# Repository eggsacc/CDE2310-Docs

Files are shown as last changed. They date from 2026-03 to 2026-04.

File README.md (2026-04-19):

# CDE2310 AY2526 S2 Group 5 


[]()

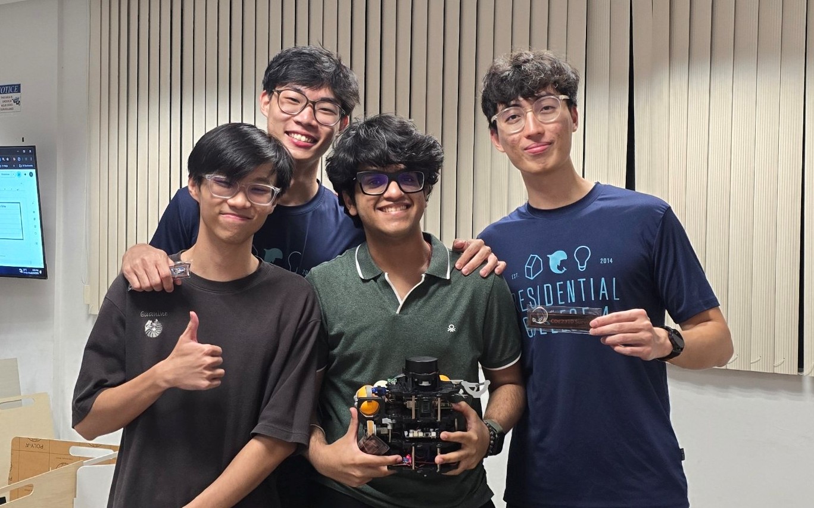
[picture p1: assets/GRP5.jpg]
grp5


[Watch the Mission Recording here](https://www.youtube.com/watch?v=zkyW6KsJtYI)

## Mission Overview
The main objective of this project is to design, create and validate an autonomous mobile robot (AMR system) based on the Turtlebot3 system to simulate intralogistics operations in a simulated smart warehouse environment. The AMR system must be capable of autonomously navigating an unknown maze-like environment while constructing a map of the environment, localizing itself and carrying out a series of tasks to deliver three ping pong balls into pre identified receptacles (static and dynamic) without human intervention or line-following methods.

---

## Mission Summary

| Station | Description | Status |
|---|---|---|
| **Station A** | Static delivery — detect QR/ArUco marker, align, and dispense 3 ping pong balls into a fixed receptacle in a timed sequence | 🟢 Completed |
| **Station B** | Dynamic delivery — track an oscillating motorised platform and dispense 3 ping pong balls onto the moving target | 🟢 Completed |
| **Station C/D** *(Bonus)* | Lift lobby → API call to summon lift → ascend to Level 2 → navigate to Station D and perform final delivery | 🚫 Aborted |

**Key constraints:**
- Full 25-minute window covers setup, mission execution, and arena cleanup
- No teleoperation once the mission clock starts
- Maximum 6 landmark markers (2 per delivery zone)
- Line-following navigation is **not permitted**; the robot must autonomously map and navigate
- RViz map screen recording is mandatory for all attempts

---

## Robot

Sexiest robot!

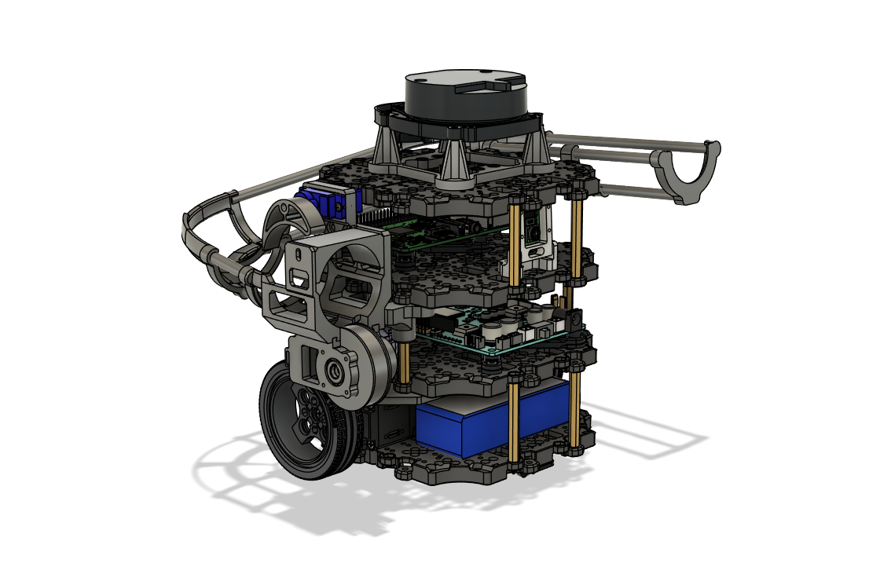
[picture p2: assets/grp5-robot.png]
robot

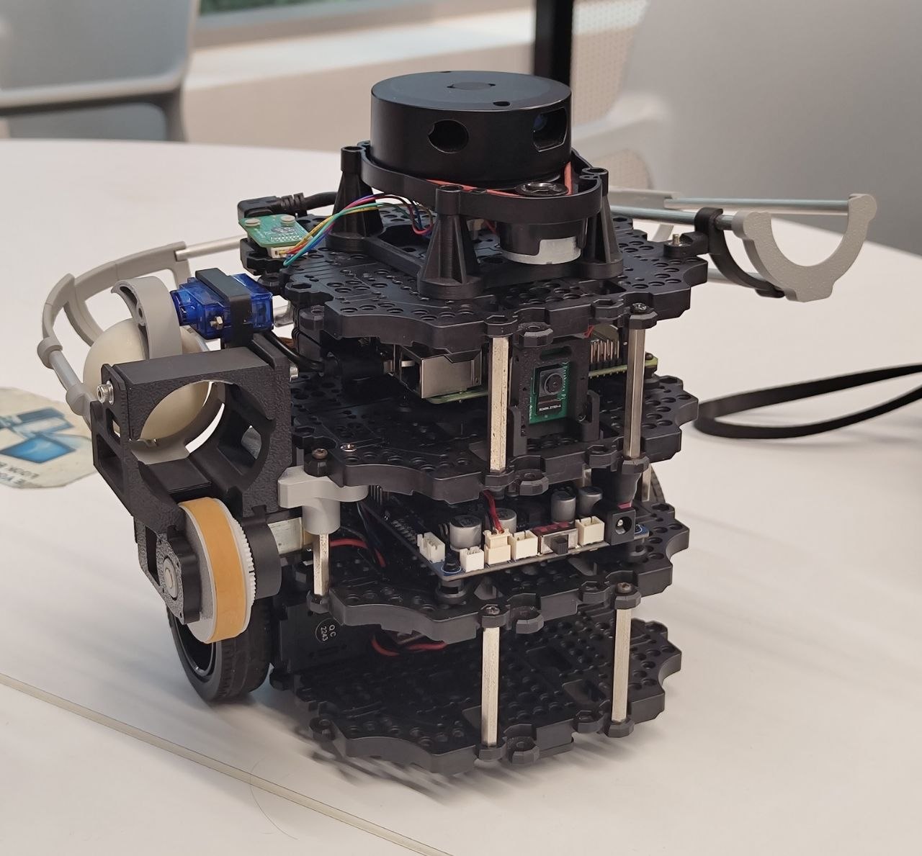
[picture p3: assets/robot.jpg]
robot

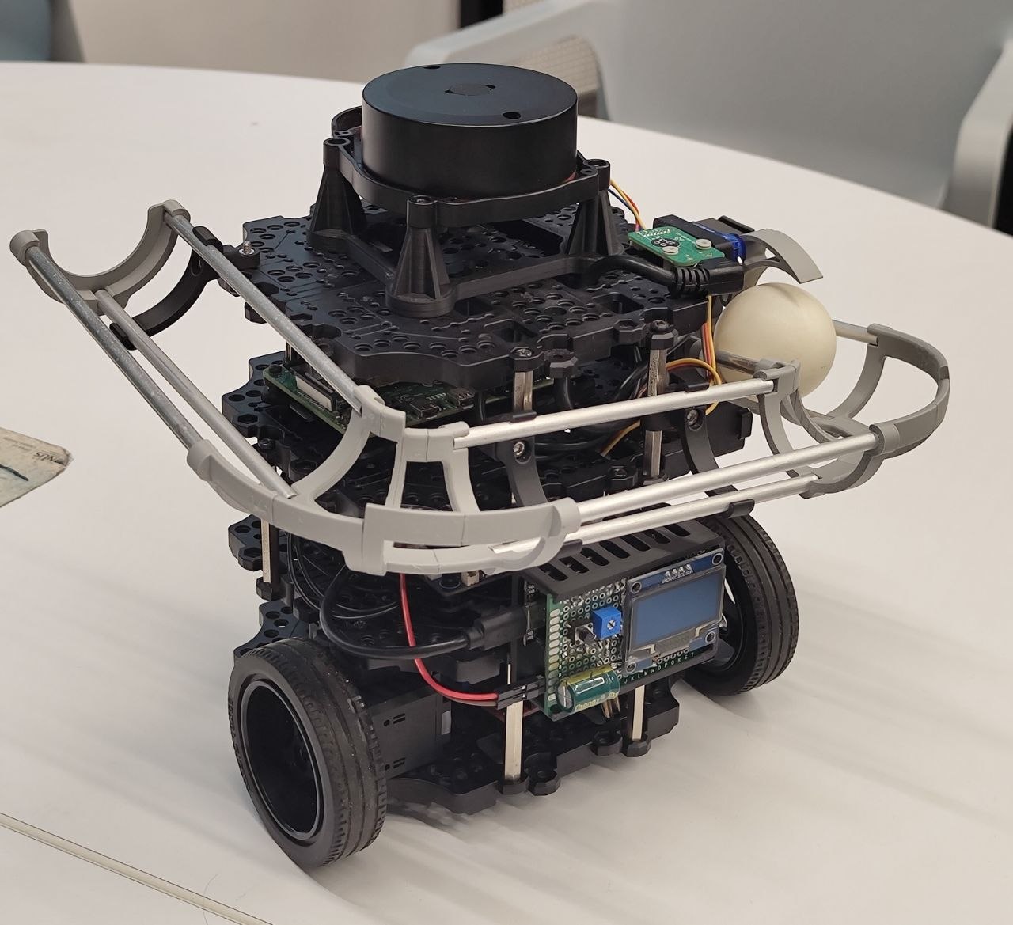
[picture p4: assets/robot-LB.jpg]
robot

## Repository Structure

```
├── README.md ← you are here
├── CHANGELOG.md
├── .gitignore
├── docs/
│ ├── 01-requirements/
│ ├── 02-con-ops/
│ ├── 03-high-level-design/
│ ├── 04-subsystem-design/
│ │ ├── software.md
│ │ ├── hardware.md
│ │ └── electronics.md
│ ├── 05-icd/
│ ├── 06-testing/
│ ├── 07-user-manual/
│ └── 08-application-notes/
│
├── end-user-docs/
├── software/
│   ├── arduino/
│   │   └── launcher_firware.ino
│   ├── remote-pc/
│   │   ├── auto_nav/
│   │   │   ├── auto_nav/
│   │   │   ├── resource/
│   │   │   ├── test/
│   │   │   ├── package.xml
│   │   │   ├── setup.cfg
│   │   │   └── setup.py
│   │   └── nav2params/
│   ├── rpi/
│   │   └── launcher_commander/
│   │       ├── launcher_commander/
│   │       ├── resource/
│   │       ├── test/
│   │       ├── package.xml
│   │       ├── setup.cfg
│   │       └── setup.py
│   └── README.md
│
├── hardware/
│ ├── BOM
│ ├── Main assembly (CAD)
│ ├── Assembly guide
│ ├── 3D print STLs
│ └── manufacturing-guide.md
│
├── electronics/
│ ├── launcher-controller.md
│ └── power-budget
```

---

## Team

| Member | Role | GitHub |
|---|---|---|
| Gary chen | Software lead (ROS 2, SLAM, navigation) | @garychen177 |
| Wang yizhang | Hardware lead (payload mechanism) | @eggsacc |
| Gregorius Nicholas Sutedja | Electronics lead (wiring, power, sensors) | @Nikidudu |
| Garg Divyansh | Systems lead (SDD, ICD, testing, integration) | @garg-divyansh |

---

## Getting Started

### Prerequisites

- Ubuntu 22.04
- ROS 2 Humble ([installation guide](https://docs.ros.org/en/humble/Installation.html))
- TurtleBot3 packages

```bash
sudo apt install ros-humble-turtlebot3* ros-humble-navigation2 ros-humble-nav2-bringup
```
## Software Codebase setup
- [Remote PC Codebase](https://github.com/eggsacc/CDE2310-Docs/tree/main/remote_pc_codebase)

### Launch (full mission)

```bash
ros2 run auto_nav mainlaunch
```

> A single launch file is targeted for the full robot operation (bonus scoring criterion v).

---

## Software Architecture

> Detailed breakdown in [`docs/04-subsystem-design/software.md`](docs/04-subsystem-design/software.md)

Key ROS 2 nodes:

| Node | Description |
|---|---|
| `navigation_node` | Nav2-based autonomous navigation and SLAM |
| `marker_detection_node` | RPi Camera V2 — QR/ArUco marker detection and pose estimation |
| `payload_node` | Controls the ping pong ball dispensing mechanism |
| `mission_manager_node` | Top-level state machine coordinating the delivery sequence |
| `lift_api_node` *(bonus)* | Handles API calls to summon and command the lift at Station C |

---

## Contributing

### Branch Naming

Branches should follow the format `<type>/<short-description>` using lowercase and hyphens:

| Type | When to use | Example |
|---|---|---|
| `feat/` | New feature or capability | `feat/aruco-docking` |
| `fix/` | Bug fix | `fix/lidar-wraparound` |
| `docs/` | Documentation only | `docs/update-icd` |
| `test/` | Tests or validation | `test/docking-alignment` |
| `hw/` | Hardware / CAD changes | `hw/payload-mount-v2` |
| `sw/` | Software changes not covered above | `sw/feat-docking-params` |

### Commit Messages

Commits follow the [Conventional Commits](https://www.conventionalcommits.org/) format:

```
<type>(<scope>): <short description>
```

| Type | When to use | Example |
|---|---|---|
| `feat` | New feature added | `feat(docking): add three-phase ArUco docking` |
| `fix` | Bug fix | `fix(fsm): cancel nav goal on state change` |
| `docs` | Documentation update | `docs(sw): update FSM state diagram` |
| `test` | Tests or validation | `test(docking): add alignment tolerance test` |

- **Scope** is the subsystem or file affected (e.g. `docking`, `fsm`, `exploration`, `hardware`)
- Keep the description short and in the imperative mood ("add", "fix", "update" , not "added" or "fixes")

---

## Versioning

This project follows [Semantic Versioning 2.0.0](https://semver.org/).

```
MAJOR.MINOR.PATCH
  │      │     └─ backward-compatible bug fixes
  │      └─────── new functionality, backward compatible
  └────────────── breaking changes
```

### Changelog

All notable changes are recorded in [`CHANGELOG.md`](CHANGELOG.md), following the [Keep a Changelog](https://keepachangelog.com/en/1.1.0/) format. Changes are grouped under:

- **Added** — new features
- **Changed** — changes to existing functionality
- **Removed** — removed features
- **Fixed** — bug fixes

Unreleased changes are staged under `[Unreleased]` and moved to a versioned section upon release.

---

## Acknowledgements

Built on the [TurtleBot3](https://github.com/ROBOTIS-GIT/turtlebot3) platform by ROBOTIS.
Course module: CDE2310 Fundamentals of Systems Design, NUS College of Design and Engineering (EDIC).
Maze mission brief by Nicholas Chew, v1.0, Dec 2025.

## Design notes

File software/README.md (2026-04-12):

# Software layout

This folder contains all the ROS2 packages and nodes used in the mission. 

- `/arduino`: Firmware for launcher controller.
- `/remote-pc`: ROS2 packages to be ran locally on laptop.
- `/rpi`: ROS2 packages ran on the raspberry pi.

There are also markdown files detailing how the source code works for each node. They can be found next to the python files within each directory, under the folder `node-docs`.

## Default nodes

Under the `auto_nav` package, all nodes with names beginning with "r2" are default nodes that came with the `auto_nav` package and are unused in this mission. These are utility nodes that provide visualization/debugging of topics, hence they are left untouched.

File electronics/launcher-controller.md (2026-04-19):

# Launcher controller

- 6V power rail stepped down from OpenCR 12V output using micror buck converter
- Power rail used mainly by flywheel motor, also to power Arduino Nano
- SG90 servo is powered from Arduino Nano 5V output due to noise (servo jitters if powered from same rail as flywheel)
- Arduino connected to Raspberry Pi via USB

## Schematic

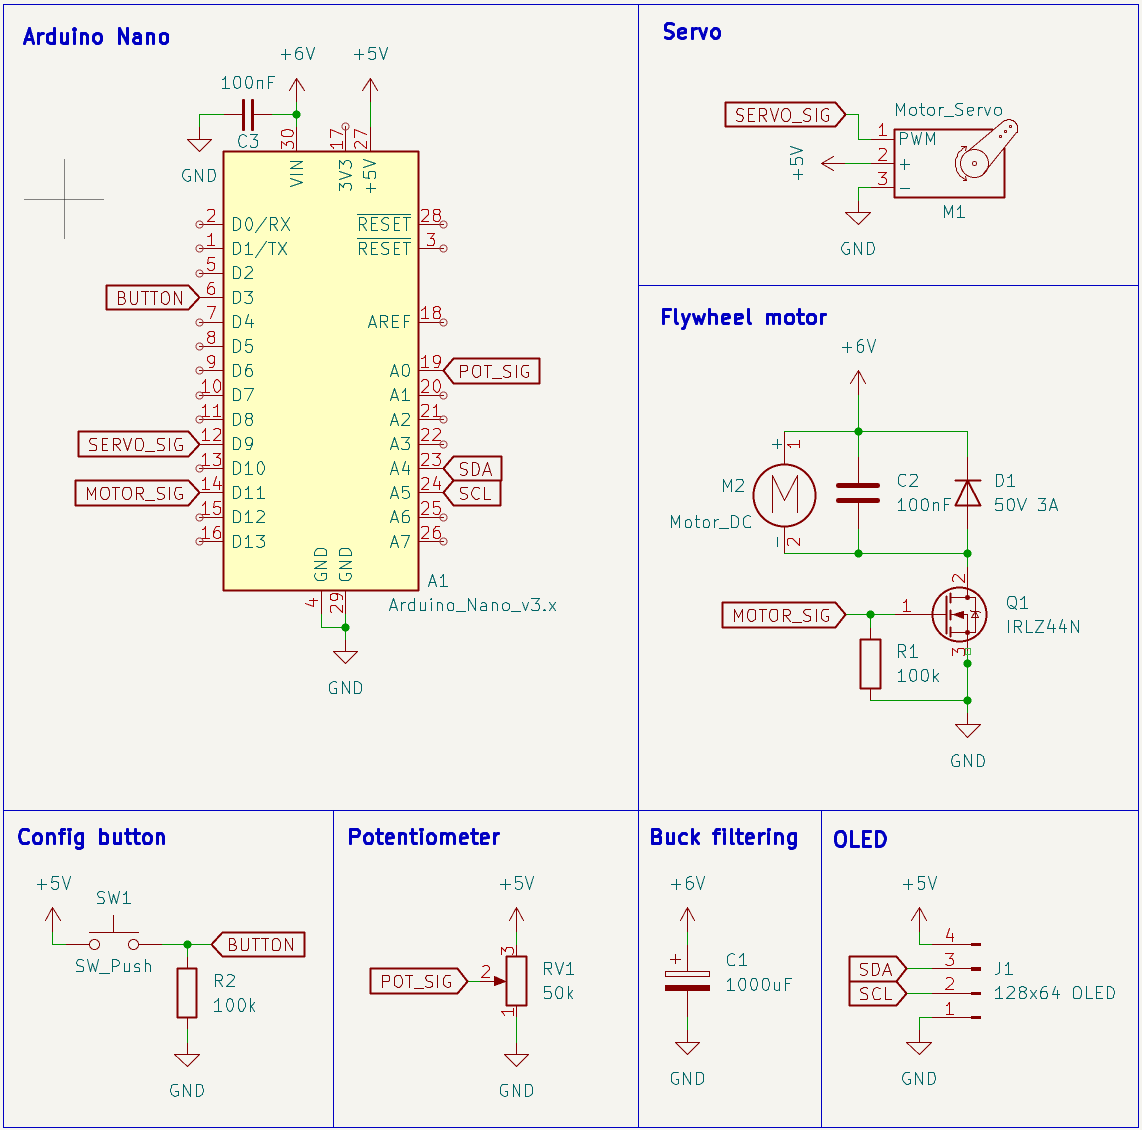
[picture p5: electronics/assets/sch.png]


## PCB

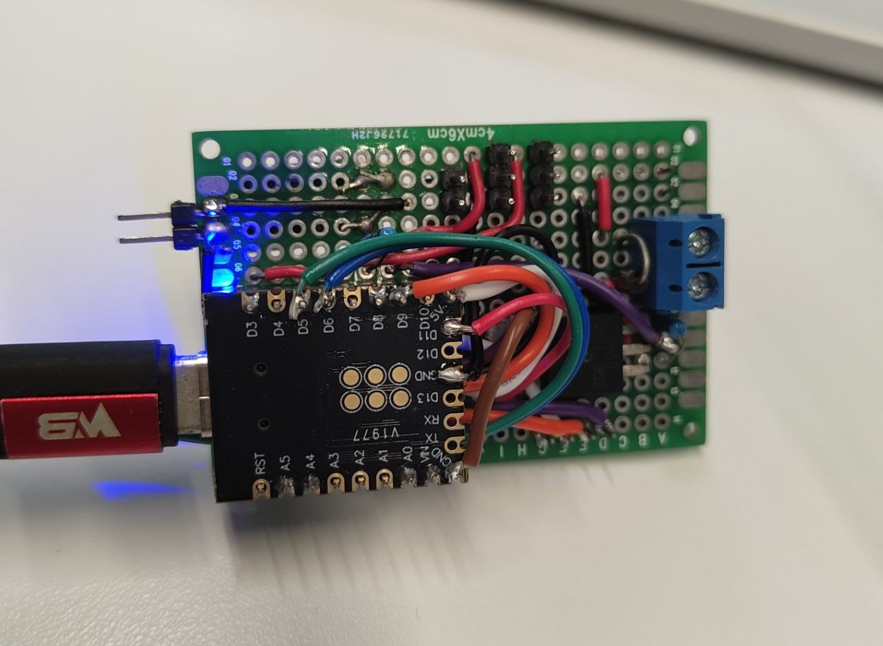
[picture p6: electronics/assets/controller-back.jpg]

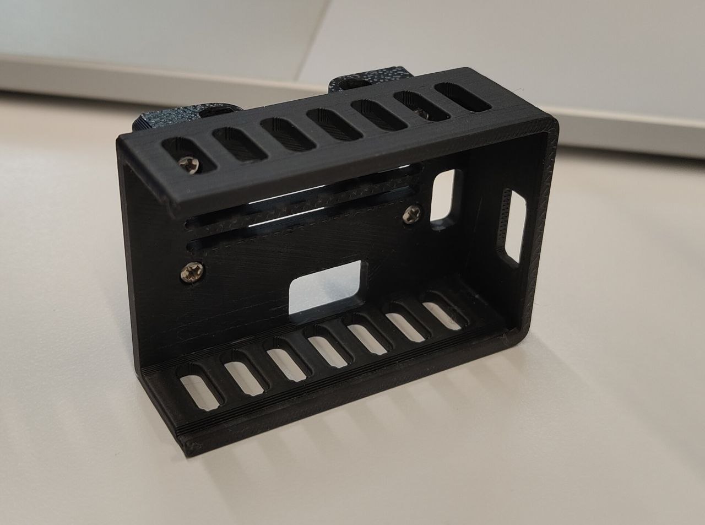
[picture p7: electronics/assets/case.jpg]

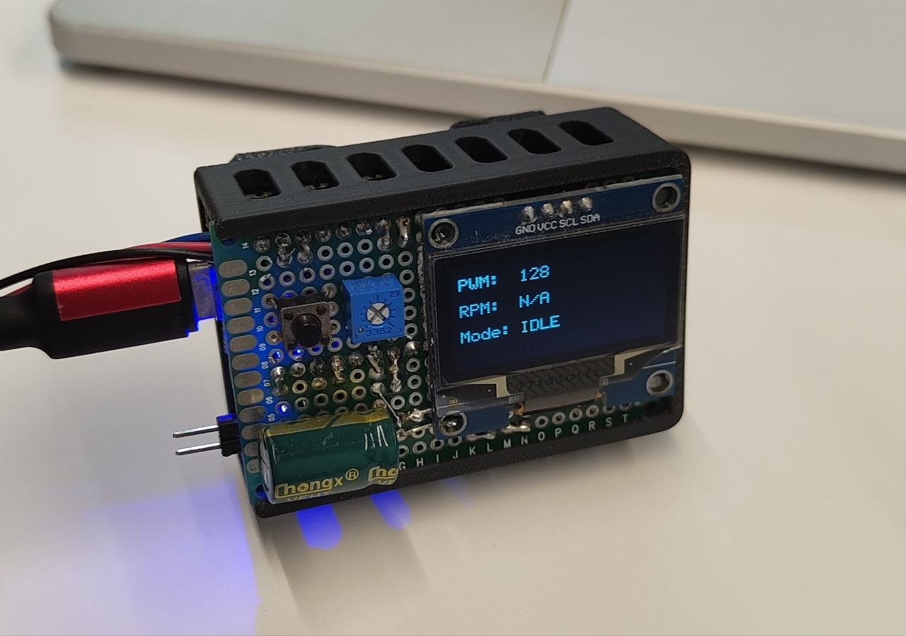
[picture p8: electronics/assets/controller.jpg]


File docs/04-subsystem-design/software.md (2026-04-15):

## 1. Overview

The software stack is implemented as a distributed ROS 2 Humble system spanning three compute layers: a remote PC, an onboard Raspberry Pi, and an Arduino-based launcher controller. The remote PC is responsible for essentially all high-level mission logic — FSM coordination, exploration, docking, perception, and launcher sequencing. The Raspberry Pi is reduced to a thin serial bridge between ROS 2 and the Arduino. The Arduino executes the low-level launcher actuation sequence in response to primitive commands received over serial.

At the system level, `fsm_controller.py` acts as the mission coordinator. It publishes mission states on `/states`, monitors execution feedback on `/operation_status`, and decides whether the robot should continue exploring, begin docking, or fire the launcher (static or dynamic). `exploration.py` performs frontier-based exploration using the live occupancy grid and Nav2's `NavigateToPose` action interface, while `docking.py` performs precision marker-based docking using TF and LIDAR.

`aruco_detector2.py` also runs on the remote PC. It subscribes to the compressed camera stream forwarded from the Raspberry Pi, detects ArUco markers, and publishes per-marker transforms into the TF tree as `aruco_marker_<id>`. These transforms are consumed by the rest of the stack for marker discovery, exploration, docking alignment, and dynamic-launch timing.

Launcher sequencing (both static and dynamic modes) is centralised in `dynamic_launch.py` on the remote PC. It emits primitive commands (`SPIN`, `FIRE`, `STOP`) on the `/arduino_cmd` topic, which a Raspberry Pi serial-bridge node forwards over USB to the Arduino. The Arduino firmware executes the flywheel + feeder hardware actions and reports back on serial; those responses are surfaced as `/arduino_response` messages for logging.

This architecture separates mission planning, perception, and low-level actuation into clear subsystems. Most computation lives on the remote PC, with only camera streaming and Arduino I/O pushed onto the Raspberry Pi.

## 2. System Architecture

The software is organised into three deployment tiers and four functional layers.

### Deployment tiers

**Remote PC**
- `fsm_controller.py` — central mission state machine
- `exploration.py` — frontier exploration and Nav2 goal dispatch
- `docking.py` — precision docking controller
- `aruco_detector2.py` — ArUco detection and TF publishing
- `dynamic_launch.py` — static and dynamic launch controller

**Raspberry Pi**
- Camera driver publishing `/camera/image_raw/compressed`
- Arduino serial bridge node forwarding `/arduino_cmd` ↔ serial (and surfacing `/arduino_response`)

**Arduino**
- `launcher_firmware.ino` — low-level launcher motor / feeder control over serial

### Functional layers

**Perception layer**
Implemented on the remote PC by `aruco_detector2.py`. It subscribes to `/camera/image_raw/compressed` (`sensor_msgs/CompressedImage`), decodes frames to grayscale, runs `cv2.aruco.detectMarkers` against the `DICT_4X4_50` dictionary at a fixed rate (default 20 Hz), estimates pose with `solvePnP` (IPPE_SQUARE) using hard-coded intrinsics and the configured `marker_size`, and broadcasts each marker as `aruco_marker_<id>` with parent frame `camera_optical_frame`. This TF output is the main perception product consumed by the rest of the stack.

**Mission management layer**
Implemented on the remote PC by `fsm_controller.py`. This node is the top-level coordinator for the mission. It publishes mission commands on `/states`, watches `/operation_status` for completion or failure feedback, and transitions between `EXPLORE` / `EXPLORE_<id>`, `DOCK_<id>`, `STATIC_LAUNCH`, `DYNAMIC_LAUNCH`, and `END`. Marker discovery is performed by directly scanning the TF tree for `aruco_marker_<id>` frames rather than through a dedicated topic.

**Navigation and docking layer**
The navigation layer is split across `exploration.py` and `docking.py`, both on the remote PC. During exploration, `exploration.py` subscribes to `/map`, detects frontiers in the occupancy grid, filters them by wall clearance and neighbour clustering, and sends navigation goals through the Nav2 `NavigateToPose` action server. It also caches the poses of every discovered `aruco_marker_<id>` frame in the `map` frame, enabling it to dispatch directed "head toward this marker" goals when the FSM commands `EXPLORE_<id>`. When docking is requested, `docking.py` takes over direct motion control via `/cmd_vel` and performs a three-phase pipeline: odometry-based navigation to a standoff pose (45 cm), TF-based fine alignment to 40 cm, and LIDAR-based final approach to 20 cm.

**Actuation layer**
All launcher sequencing lives in `dynamic_launch.py` on the remote PC. In static mode it fires three balls with a 5.5 s cooldown; in dynamic mode it polls TF for the target marker, requires a fresh (≤ 0.2 s old) transform, applies a `launch_delay` lead time, and fires up to `max_shots` rounds subject to a shot cooldown. It publishes primitive `SPIN` / `FIRE` / `STOP` strings on `/arduino_cmd`. A Raspberry Pi serial-bridge node forwards these to the Arduino over USB; Arduino text replies come back on `/arduino_response` for logging. The Arduino firmware executes the actual flywheel and feeder timing.

### Inter-node communication

The main software interfaces are:
- `/states` — mission command bus from `fsm_controller.py` to exploration, docking, and launch nodes.
- `/operation_status` — execution feedback bus from docking and launcher nodes back to `fsm_controller.py`.
- `/map` — occupancy grid (Cartographer) consumed by the exploration subsystem.
- `/cmd_vel` — direct velocity output used by `docking.py` and, via Nav2, by exploration.
- `/arduino_cmd`, `/arduino_response` — launcher primitive commands and raw Arduino replies, bridged to serial on the Raspberry Pi.
- TF tree (`aruco_marker_<id>`) — perception output shared across exploration, docking, FSM logic, and dynamic launch logic.
- Serial link (Raspberry Pi ↔ Arduino) — low-level launcher command and completion channel, hidden behind the `/arduino_cmd` / `/arduino_response` topic pair.

### End-to-end control flow

1. `aruco_detector2.py` detects markers and publishes their TF frames.
2. `fsm_controller.py` polls TF for `aruco_marker_<id>` frames and publishes the current state on `/states`.
3. `exploration.py` responds to `EXPLORE` / `EXPLORE_<id>` by generating frontier or marker-directed Nav2 goals.
4. When a target marker comes within 0.8 m of `base_link`, `fsm_controller.py` commands `DOCK_<id>`.
5. `docking.py` performs precision alignment and publishes `DOCK_DONE`, `DOCK_FAIL`, or `TIMEOUT` on `/operation_status`.
6. The FSM maps the completed marker ID to a launch state (`STATIC_LAUNCH` for marker 1, `DYNAMIC_LAUNCH` for marker 2).
7. `dynamic_launch.py` sequences the shots, publishing `SPIN` / `FIRE` / `STOP` on `/arduino_cmd`. The RPi serial bridge forwards them to the Arduino.
8. The FSM receives `LAUNCH_DONE` (or `LAUNCH_TIMEOUT` / `LAUNCH_INCOMPLETE`) and either resumes exploration or ends the mission.

## 3. Node Summary

| Node | File | Runs on | Description |
|---|---|---|---|
| `fsm_controller` | `fsm_controller.py` | Remote PC | Top-level mission state machine. Publishes mission commands on `/states`, monitors `/operation_status`, scans the TF tree for nearby ArUco markers, and selects whether the robot should explore, dock, launch (static/dynamic), or end. |
| `explorer` | `exploration.py` | Remote PC | Frontier-based exploration node. Subscribes to the occupancy grid, selects wall-clear, well-clustered frontiers, sends goals through Nav2's `NavigateToPose`, caches discovered ArUco marker map poses, and can switch to a directed marker approach on `EXPLORE_<id>`. |
| `docking_node` | `docking.py` | Remote PC | Precision docking controller for ArUco targets. Executes a three-phase docking sequence: odometry-based standoff navigation (45 cm), TF-based EMA-smoothed fine approach (40 cm) with 360° recovery spin on marker loss, and LIDAR-based final approach (20 cm). |
| `aruco_detector` | `aruco_detector2.py` | Remote PC | Vision node for ArUco detection. Subscribes to the compressed camera stream, runs `DICT_4X4_50` detection at 20 Hz, solves PnP per marker, and broadcasts each detected marker into the TF tree as `aruco_marker_<id>` under `camera_optical_frame`. |
| `dynamic_launcher_node` | `dynamic_launch.py` | Remote PC | Unified launch controller. Handles `STATIC_LAUNCH` (3 balls, 5.5 s cooldown) and `DYNAMIC_LAUNCH` (TF-freshness-gated firing with launch delay, shot cooldown, and timeouts). Emits `SPIN` / `FIRE` / `STOP` on `/arduino_cmd` and reports `LAUNCH_DONE` / `LAUNCH_TIMEOUT` / `LAUNCH_INCOMPLETE`. |
| Arduino serial bridge | (bridge node) | Raspberry Pi | Thin node that forwards `/arduino_cmd` strings to the Arduino over USB and republishes Arduino text replies on `/arduino_response`. |
| `launcher_firmware` | `launcher_firmware.ino` | Arduino | Low-level launcher controller. Drives the flywheel motor and feeder servo in response to `SPIN`, `FIRE`, and `STOP` primitives received over serial, and reports status back to the RPi. |

## 4. Topics and Interfaces

### 4.1 ROS Topics

| Name | Type | Publisher | Subscriber | Description |
|---|---|---|---|---|
| `/states` | `std_msgs/String` | `fsm_controller` | `explorer`, `docking_node`, `dynamic_launcher_node` | Main mission command topic. Values include `EXPLORE`, `EXPLORE_<id>`, `DOCK_<id>`, `STATIC_LAUNCH`, `DYNAMIC_LAUNCH`, `END`. |
| `/operation_status` | `std_msgs/String` | `docking_node`, `dynamic_launcher_node` | `fsm_controller` | Execution feedback. Values include `DOCK_DONE`, `DOCK_FAIL`, `TIMEOUT`, `LAUNCH_DONE`, `LAUNCH_TIMEOUT`, `LAUNCH_INCOMPLETE`, `NAV_FAIL`, `MARKER_LOST`, `MAP_DONE`. |
| `/map` | `nav_msgs/OccupancyGrid` | Cartographer | `explorer` | Live occupancy grid used for frontier detection and exploration planning. |
| `/scan` | `sensor_msgs/LaserScan` | TurtleBot3 LIDAR driver | `docking_node` | LIDAR scan used for final close-range docking distance control. |
| `/camera/image_raw/compressed` | `sensor_msgs/CompressedImage` | Raspberry Pi camera driver | `aruco_detector` | Compressed camera stream used for ArUco marker detection. |
| `/cmd_vel` | `geometry_msgs/Twist` | `docking_node`, Nav2 controller, `explorer` (stop commands only) | TurtleBot3 base driver | Velocity command topic used for robot motion. During precision docking, `docking_node` directly commands the robot. |
| `/arduino_cmd` | `std_msgs/String` | `dynamic_launcher_node` | RPi serial bridge | Primitive launcher commands (`SPIN`, `FIRE`, `STOP`) to be relayed to the Arduino. |
| `/arduino_response` | `std_msgs/String` | RPi serial bridge | `dynamic_launcher_node` | Raw Arduino replies surfaced back onto ROS for logging. |
| `/current_marker` | `std_msgs/Int32` | (detection node) | `dynamic_launcher_node` | Optional marker-ID hint used for logging in dynamic mode. |

### 4.2 ROS Actions

| Name | Type | Client | Server | Description |
|---|---|---|---|---|
| `navigate_to_pose` | `nav2_msgs/action/NavigateToPose` | `explorer` | Nav2 | Action interface used by the exploration node to send frontier and marker-directed goals for autonomous movement. |

### 4.3 TF Interfaces

| Frame / Interface | Producer | Consumer | Description |
|---|---|---|---|
| `aruco_marker_<id>` | `aruco_detector` | `fsm_controller`, `explorer`, `docking_node`, `dynamic_launcher_node` | Per-marker TF frame broadcast from the camera frame after pose estimation. Used for marker discovery, docking alignment, and dynamic launch timing. |
| `base_link` | Robot TF tree | `fsm_controller`, `docking_node`, `dynamic_launcher_node` | Robot base frame used for marker distance checks and docking control. |
| `odom` | Robot TF tree | `docking_node` | Used during Phase 1 docking to navigate to a standoff pose in odometry coordinates, and by the Phase 2 recovery spin to track cumulative yaw. |
| `map` | Cartographer / localisation stack | `explorer` | Used to store robot pose and discovered marker positions in the global map frame. |
| `camera_optical_frame` | Camera TF tree | `aruco_detector` | Parent frame for ArUco marker transforms published by the perception node. |

### 4.4 Serial Interface (Raspberry Pi ↔ Arduino)

| Interface | Sender | Receiver | Description |
|---|---|---|---|
| Serial command channel | RPi serial bridge | `launcher_firmware` | Forwards `SPIN`, `FIRE`, and `STOP` strings received on `/arduino_cmd` to the Arduino over USB. |
| Serial status channel | `launcher_firmware` | RPi serial bridge | Returns launcher runtime status; the bridge re-publishes each line as `/arduino_response` for logging. |

### 4.5 Notes

- No custom ROS services are defined in the current subsystem implementation.
- `aruco_detector2.py` publishes marker information through TF rather than through a dedicated ROS topic.
- All launch sequencing (static and dynamic) is performed on the remote PC by `dynamic_launch.py`. The Raspberry Pi and Arduino are not responsible for counting shots or enforcing cooldowns.
- Launcher status values reflect the current implementation: `LAUNCH_DONE` on success, `LAUNCH_TIMEOUT` if no shot fires within the overall timeout, and `LAUNCH_INCOMPLETE` if the timeout hits after a partial sequence.

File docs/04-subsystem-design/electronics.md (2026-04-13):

# Electronics Architecture

Below shows the breakdown of the electrical subcomponents:

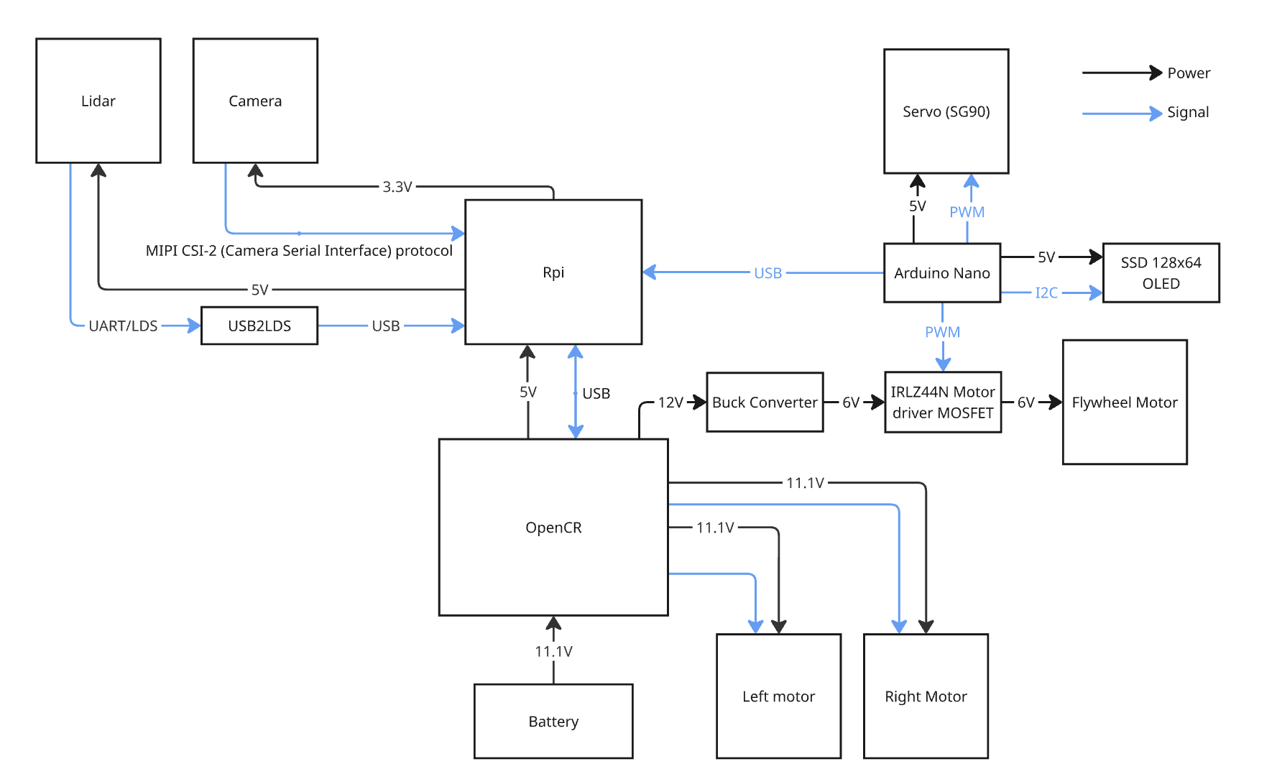
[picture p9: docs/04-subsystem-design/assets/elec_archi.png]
electronic architecture


The key components added to complete the mission is as follows:

- A SG90 servo motor for the feeding mechanism
- A buck converter converting the 12V from the OpenCR board into 6V for the DC motor
- A DC motor to spin the flywheel
- IRLZ44N MOSFET used to control motor speed
- Arduino Nano to offload launching sequence & launcher control
- SSD 128x64 OLED screen to look cool (and display real-time mission status)

## Launcher
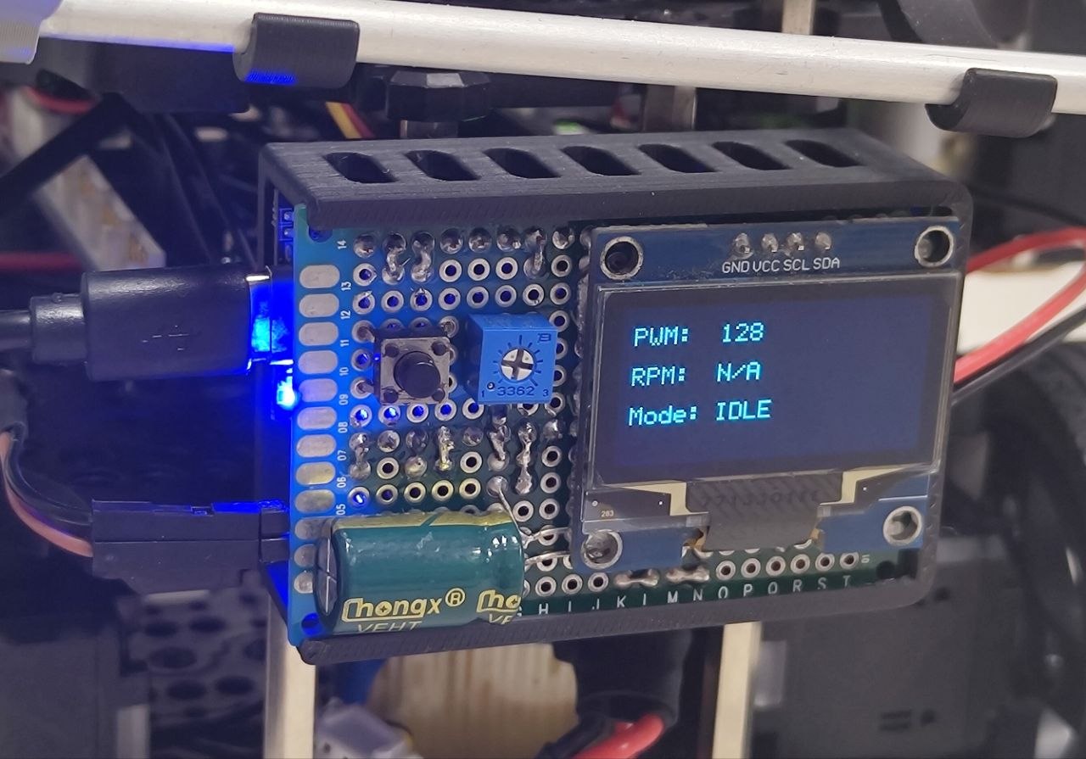
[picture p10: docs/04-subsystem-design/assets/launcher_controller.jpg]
launcer controller photo


Below is the electronics schematic for the launcher subsystem. To make the launcher truly a "subsystem", it features an integrated controller using the Arduino Nano. The launcher controller controls the servo and the flywheel motor. It also features a push-button and potentiometer input to allow the user to adjust the motor speed on-the-fly. A small OLED display is used to show real-timer operation status (and look cool).

### Features
- Press button to enter config mode.
- In config mode, turn potentiometer to adjust motor speed.
- Press button again to exit config mode and save motor PWM.

The controller is connected to the Raspberry Pi SBC via USB, and is supplied +6V power from a buck converter for the flywheel motor.

### Commands
- `"SLAUNCH"`: Execute static launch sequence
- `"DLAUNCH"`: Execute dynamic launch sequence
- `"SPIN"`: Starts flywheel
- `"FIRE"`: Feed a single ping pong ball
- `"PING"`: Serial connection check. Returns "PONG" if available.

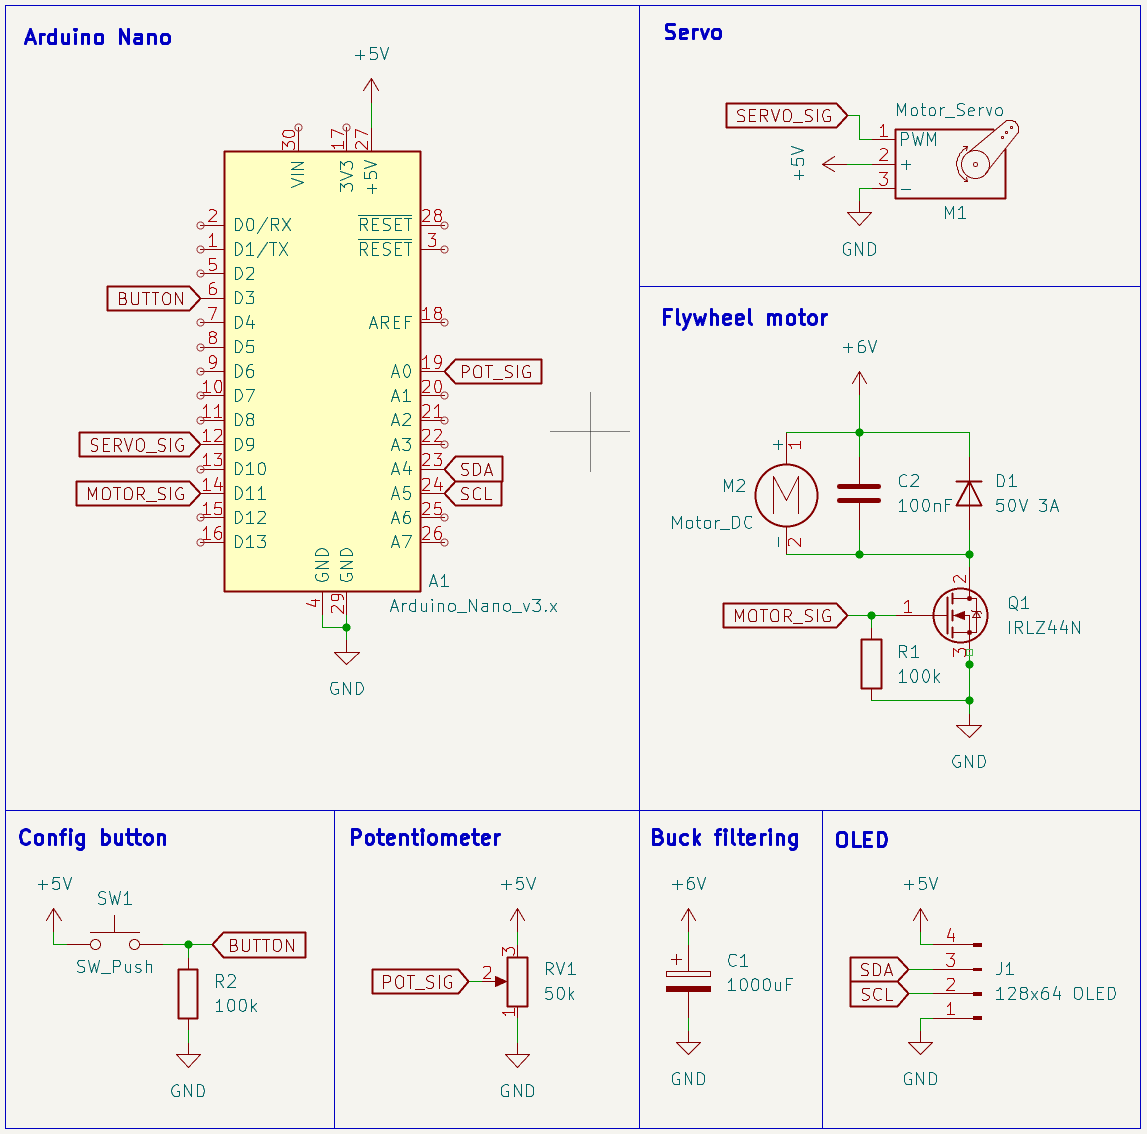
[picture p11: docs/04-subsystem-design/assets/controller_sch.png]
launcher electronic diagram


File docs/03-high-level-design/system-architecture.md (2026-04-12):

# System Architecture

## Overview

The Autonomous Mobile Robot (AMR) system is composed of four primary subsystems:

1. Navigation Subsystem  
2. Vision Subsystem  
3. Payload Subsystem  
4. Mission Manager (Finite State Machine)

These subsystems communicate through ROS 2 topics and TF transforms.

---

## System Architecture Diagram
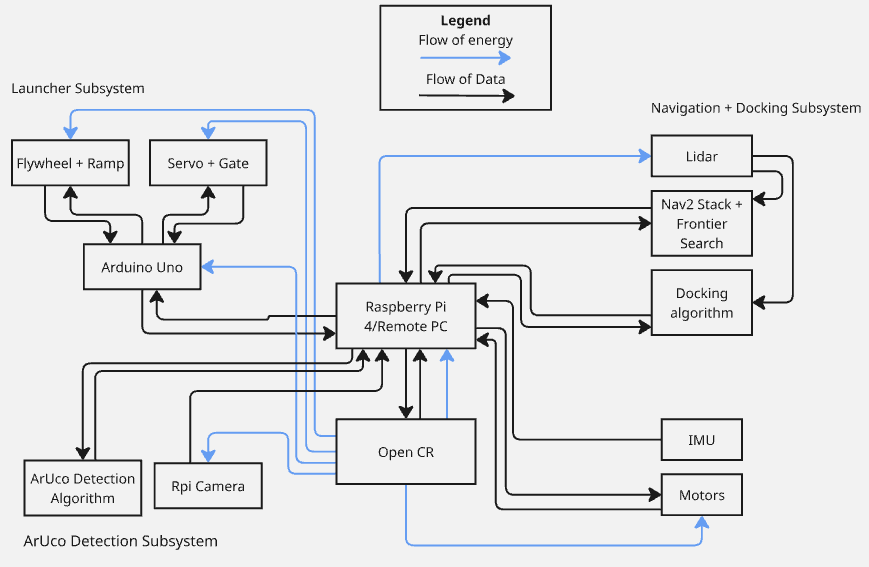
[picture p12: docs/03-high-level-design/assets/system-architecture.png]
system-architecture-diagram

---

## Subsystem Description

### Navigation Subsystem
Responsible for mapping and path planning using SLAM Toolbox and Nav2.

Inputs:
- 'EXPLORE' state from FSM
- /scan (LiDAR)
- /odom (odometry)

Outputs:
- Velocity commands to robot
- Completion status/error messages to FSM

---

### Vision Subsystem
Detects ArUco markers and estimates pose using OpenCV and PnP algorithm. Also controls docking of the robot in front of the receptacle via the ArUco Marker Detection.

Inputs:
- 'DOCK' status from FSM

Outputs:
- Marker pose (tvec, quaternion)
- TF transforms
- Docking completion status/error messages to FSM

---

### Payload Subsystem
Controls the flywheel launcher and ball feeding mechanism.

Inputs:
- 'LAUNCH' status from FSM

Outputs:
- Completion status/error messages to FSM

---

### Mission Manager (FSM)
Coordinates all subsystems based on mission state.

Inputs:
- Current Operation Status and Error Messages

Outputs:
- Current Bot State
- ArUco Marker ID for docking and launching

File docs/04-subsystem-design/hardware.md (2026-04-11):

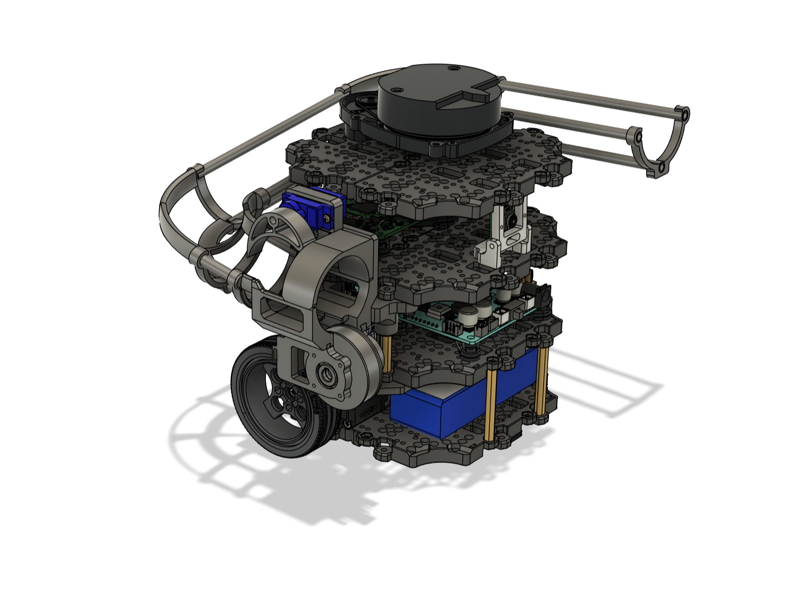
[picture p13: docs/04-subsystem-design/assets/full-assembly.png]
full assembly


## 1) Hardware design overview
This document provides an overview of the hardware architecture for Turtlebot. The design focuses on modularity, compact integration and manufacutability, combining various 3D printed and off-the-shelf components to produce a clean, professional aesthetic.

## 2) Payload system architecture
- Launcher: single bottom flywheel
- Ball storage: skeletal ramp
- Ball feeder: servo driven indexer

## 3) Mechanical design
### 3.1) Flywheel launcher
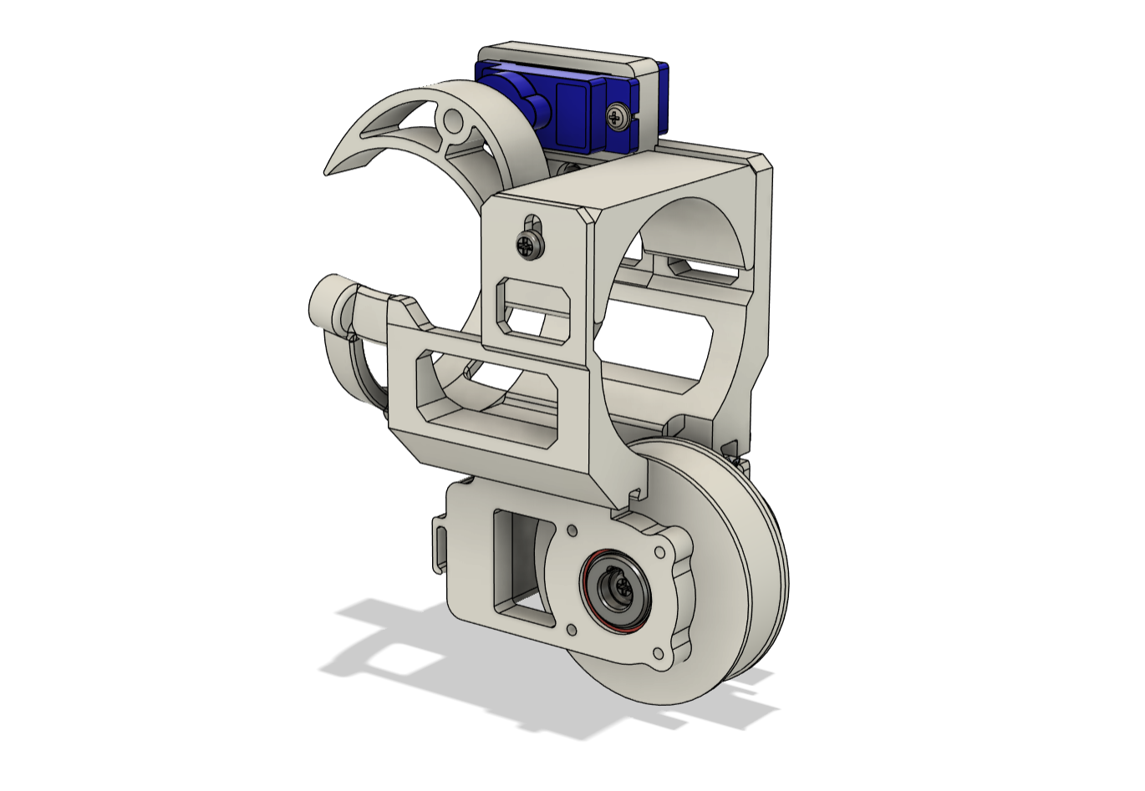
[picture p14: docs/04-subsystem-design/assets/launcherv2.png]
flylwheel launcher


Our robot uses a single, bottom-mount flywheel as the ping-pong ball launch mechanism. The design strikes a balance between manufacturability, modularity and aesthetics.

A single flywheel was chosen as the launch mechanism since:
- Launch distance is relatively short (~10cm based on chosen docking position)
- Driven by a single motor, decreasing power usage
- Simple to integrate into the space-constrained Turtlebot chasis without detrimental effects to overall CG
- Inherently introduces backspin on the ball, decreasing the chance of it bouncing out of recepticle

The flywheel uses the most common, off-the-shelf 130 Hobby DC motor (6V). This motor is optimized for low torque, high speed operations, with a rated no-load speed of up to 12,000 RPM. 

Hence, a 12:56 gear reduction is used to lower the flywheel speed and increase torque. This has the following benefits:

- Decrease motor acceleration load: motor draws less current to spin up the flywheel.
- Decrease recovery time between shots: motor experience less RPM drop per shot due to increased torque.
- Motor operates at high efficiency zone: the excess speed is traded for increased torque, allowing the motor to continue operating near the rated voltage instead of having to using a very low PWM duty cycle.

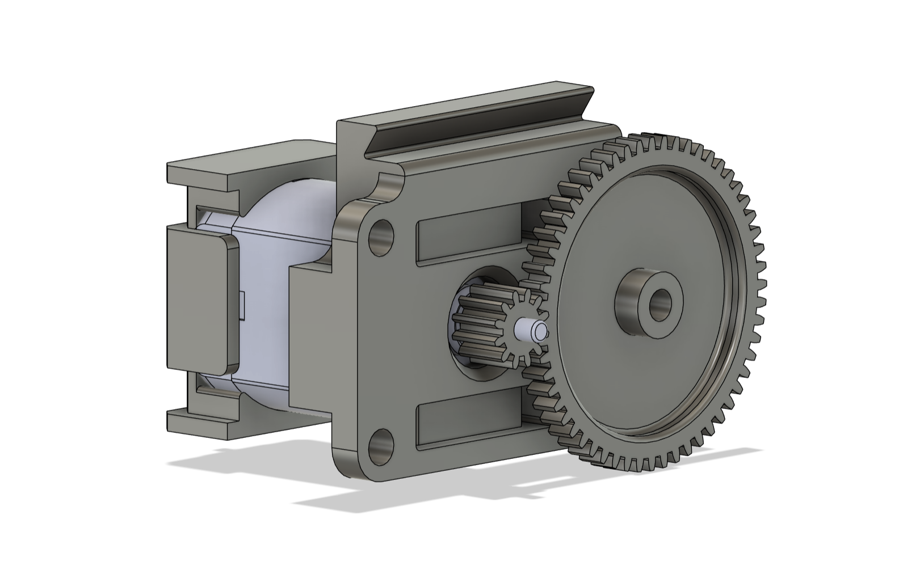
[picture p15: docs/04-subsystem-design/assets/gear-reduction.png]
gear reduction


> 3D printed helical gears were used for the first few iterations, but quickly scraped due to manufacturing limitations. 3D printers are unable to produce the intricate gear tooth features accurately, resulting in grinding and noisy operations.
> 
> Common, off-the-shelf 0.5mm module plastic gears were used instead.

### 3.2) Storage ramp
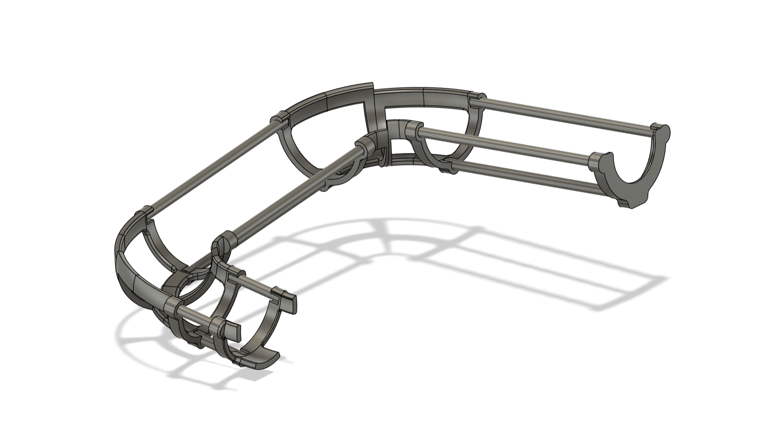
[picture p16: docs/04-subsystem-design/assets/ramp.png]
storage ramp

The ping pong ball storage ramp is fabricated using 5mm aluminium rods and 3d printed connectors. Using aluminium rods as the ball guide eliminates the need to 3D print massive ramps that often require substential support materials while contributing to the clean, minimal aesthetic.

### 3.3) Ball indexer
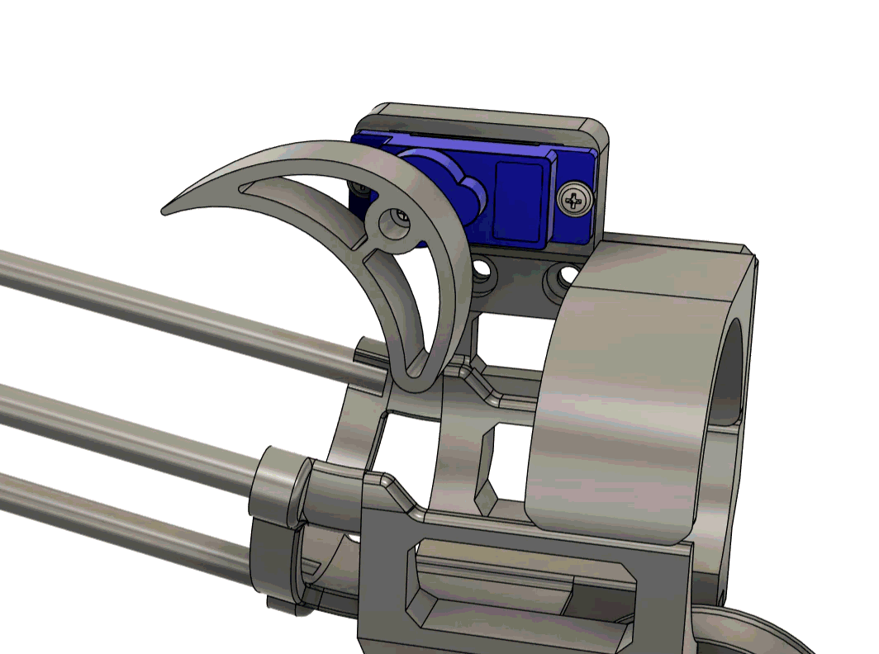
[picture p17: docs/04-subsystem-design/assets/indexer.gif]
indexer animation

A simple servo driven indexer is used to feed ping pong balls into the flywheel one at a time.

### 3.4) Camera
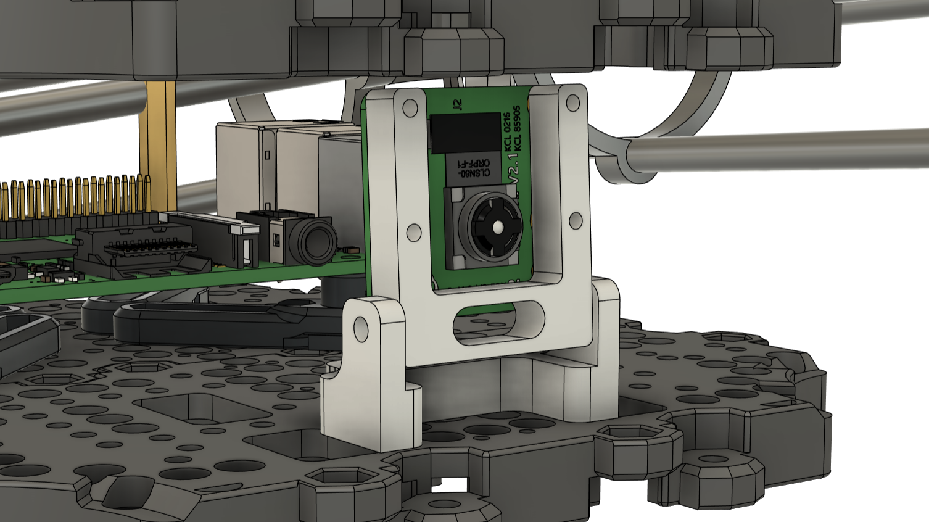
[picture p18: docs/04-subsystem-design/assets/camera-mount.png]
camera-mount

The RPI camera V2 is mounted on a simple, tilt-adjustable stand between the 3rd and 4th layer, facing the robot front.

## 4) Design features
### 4.1) Modularity
The whole hardware assembly consists of 20 different 3D printed components instead of being modelled as a single piece. This allows iterative design improvements on individual components instead of having to re-print the whole launcher.

The components are assembled together using 4 primary methods:
- Screws with heatset inserts
- Screws with inset nut
- Super glue
- Dovetail joint

Construction of the ramp using 5mm aluminium rods as ball guides also contributes to the modularity aspect. The length of the ramp could be easily modified by trimming down the rods, instead of re-printing the whole thing.

### 4.2) Adjustability
Building on the modular design aspect, the launcher assembly features some adjustable components. The ball exit hood, for example, can be adjusted vertically by loosening 2 screws to accomodate different rubber band thicknesses or the amount of flywheel contact.

adjustable-hood

The flywheel also allows lateral position adjustments since it is attached using a dovetail joint. These features allows us to adjust the launcher hardware on-the-fly, instead of redesigning in CAD and iterating multiple times.

sliding-dovetail

### 4.3) 3D printing optimization
Most of the components in the assembly requires little to no support for 3D printing, drastically increasing the ease of production and decreasing print time (time = money). The components are designed with a ground-up approach: in the prelimary design stages of each component, a single plane is established as the "ground plane" where every other geometrical feature strictly builds up from. Such a design philosophy ensures that the components do not contain any overhangs/floating features when printed from the ground plane up, eliminating supports.

### 4.4) Bearings
Low-profile bearings are integrated into the design to constrain rotational motion and enhance flywheel smoothness.
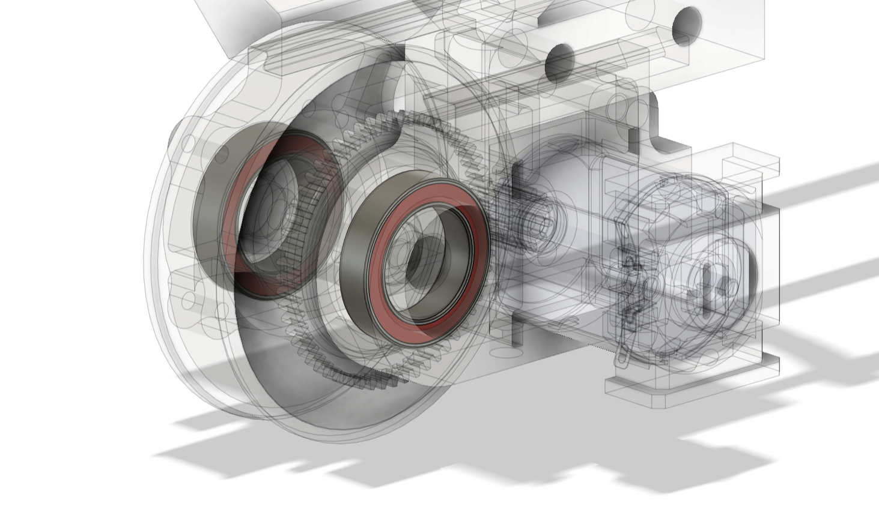
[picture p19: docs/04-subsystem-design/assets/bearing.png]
bearing


### 4.5) Design aesthetics
The design uses appropriate cut-outs, fillets and chamfers where necessary for a consistant aesthetic across components. Each component integrated seamlessly into the final assembly, contributing to a coherent appearence.

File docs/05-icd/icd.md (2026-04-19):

# Interface Control Document (ICD)

**Version:** 2.0.0
**Last updated:** 2026-04-19
**Author:** Wang Yizhang  
**Status:** Released

---

## 1. Purpose

This Interface Control Document defines how the three project subsystems communicate:

- **Software (SW)** — ROS 2 nodes and logic running on the remote PC and Raspberry Pi
- **Hardware (HW)** — compute devices, launcher controller, and physical modules
- **Electronics (EL)** — low-level electrical connections, pins, signals, and power rails

The goal is to clearly define subsystem boundaries so that each part can be developed and integrated consistently.

---

## 2. System Overview

The robot explores a maze and discovers two intermediate missions during runtime:

1. **Static delivery** — launch 3 ping pong balls into a stationary receptacle
2. **Dynamic delivery** — launch 3 ping pong balls into a moving receptacle

The robot identifies each station using pasted ArUco markers and docks to a fixed distance in front of the marker before launching.

The mission flow is:

`EXPLORE → DOCK → STATIC_LAUNCH → EXPLORE → DOCK → DYNAMIC_LAUNCH → END`

---

## 3. Subsystem Allocation

### 3.1 Software Subsystem
Runs ROS 2 nodes and mission logic.

**Remote PC**
- `fsm_controller`
- `exploration`
- `docking`
- `aruco_detector2`
- `dynamic_launch` (handles both static and dynamic launch sequencing)

**Raspberry Pi 4B**
- Camera driver (publishes `/camera/image_raw/compressed`)
- Arduino serial bridge (relays `/arduino_cmd` ↔ USB serial, republishes replies on `/arduino_response`)

### 3.2 Hardware Subsystem
Physical computing and mechatronic devices.

- Remote PC
- Raspberry Pi 4B
- Arduino Nano
- RPi Camera V2
- LDS-02 LIDAR
- SG90 servo
- 130 DC flywheel motor (6 V)
- IRLZ44N MOSFET
- OpenCR control board

### 3.3 Electronics Subsystem
Electrical interfaces and power distribution.

- Arduino Nano GPIO / PWM / I2C
- USB serial between Raspberry Pi and Arduino
- 5 V logic rail for servo and OLED
- 6 V motor rail from buck converter
- 11.1 V LiPo to OpenCR
- Common ground shared across launcher electronics

---

## 4. Interface Summary

| ID | Boundary | Interface | Purpose |
|---|---|---|---|
| IF-01 | SW ↔ SW | `/states` | Mission command topic |
| IF-02 | SW ↔ SW | `/operation_status` | Execution feedback topic |
| IF-03a | SW ↔ SW | `/arduino_cmd`, `/arduino_response` | Remote-PC launch primitives + Arduino replies (bridged on the RPi) |
| IF-03 | SW ↔ HW | USB serial (`/dev/arduino_launcher`) | Raspberry Pi bridge to Arduino launcher control |
| IF-04 | HW ↔ EL | Arduino PWM output to motor stage | Flywheel speed control |
| IF-05 | HW ↔ EL | Arduino servo output | Ball feeding mechanism |
| IF-06 | HW ↔ EL | Arduino analog input | Potentiometer tuning input |
| IF-07 | HW ↔ EL | Arduino digital input | Mode button |
| IF-08 | HW ↔ EL | Arduino I2C | OLED display |
| IF-09 | HW ↔ EL | Power rails | System power distribution |

---

## 5. SW ↔ SW Interfaces

### 5.1 `/states`

- **Type:** `std_msgs/String`
- **Publisher:** `fsm_controller`
- **Subscribers:** `exploration`, `docking`, `dynamic_launch`

**Valid values**
- `EXPLORE`
- `EXPLORE_<id>` (marker-directed exploration)
- `DOCK_<id>`
- `STATIC_LAUNCH`
- `DYNAMIC_LAUNCH`
- `END`

**Description**
This is the main command topic used by the FSM to activate the appropriate software node for each mission phase. `<id>` is the integer ArUco marker ID the FSM has locked onto (e.g. `DOCK_1`, `EXPLORE_2`).

---

### 5.2 `/operation_status`

- **Type:** `std_msgs/String`
- **Publishers:** `docking`, `dynamic_launch`
- **Subscriber:** `fsm_controller`

**Valid values**
- `DOCK_DONE`
- `DOCK_FAIL`
- `TIMEOUT`
- `LAUNCH_DONE`
- `LAUNCH_TIMEOUT`
- `LAUNCH_INCOMPLETE`
- `NAV_FAIL`
- `MARKER_LOST`
- `MAP_DONE`

**Description**
This topic reports task completion or failure back to the FSM. The FSM uses it to decide whether to continue, retry, skip the current marker, or end the mission.

---

### 5.3 `/arduino_cmd` and `/arduino_response`

- **Types:** both `std_msgs/String`
- **`/arduino_cmd`** — published by `dynamic_launch` on the remote PC, subscribed by the RPi serial bridge; values: `SPIN`, `FIRE`, `STOP`.
- **`/arduino_response`** — published by the RPi serial bridge with the Arduino's raw text reply (logging / debug only).

**Description**
All launcher shot sequencing is performed on the remote PC. The RPi bridge merely forwards the primitive command over USB serial and republishes the Arduino's text reply back onto ROS.

---

## 6. SW ↔ HW Interface

### 6.1 Raspberry Pi to Arduino serial link

- **Physical connection:** USB
- **Device alias:** `/dev/arduino_launcher`
- **Baud rate:** `115200`
- **Software endpoint:** `launcher_cmd` on Raspberry Pi
- **Hardware endpoint:** Arduino Nano running launcher firmware

**Description**  
The Raspberry Pi controls the launcher by sending serial commands to the Arduino. The Arduino handles the low-level motor and servo actuation and returns status messages.

### 6.2 Serial commands sent from Raspberry Pi to Arduino

| Command | Purpose |
|---|---|
| `PING` | Connection / readiness check |
| `SPIN` | Spin up flywheel motor |
| `FIRE` | Feed and launch one ball |
| `STOP` | Stop launcher motor |

**Note**  
Shot sequencing is controlled by the Raspberry Pi. Static and dynamic launch logic are handled in software; the Arduino only executes primitive launcher actions.

### 6.3 Serial responses sent from Arduino to Raspberry Pi

| Response | Meaning |
|---|---|
| `PONG` | Arduino is responsive |
| `READY` | Launcher is ready |
| `FIRED` | One shot completed |
| `STOPPED` | Launcher stopped |
| `ERR:NOT_READY` | Launcher not ready to fire |
| `LAUNCH_COMPLETE` | Launch sequence complete |

---

## 7. HW ↔ EL Interfaces

### 7.1 Arduino pin map

| Function | Arduino Nano pin |
|---|---|
| Motor PWM | D11 |
| Servo control | D9 |
| Potentiometer input | A0 |
| OLED SDA | A4 |
| OLED SCL | A5 |
| Mode button | D3 |

---

### 7.2 Motor control interface

- **Controller:** Arduino Nano
- **Switching device:** IRLZ44N MOSFET
- **Motor:** 130 DC motor, 6 V
- **Signal type:** PWM from D11

**Description**  
The Arduino outputs PWM on D11 to control flywheel speed through the IRLZ44N MOSFET stage.

---

### 7.3 Servo control interface

- **Controller:** Arduino Nano
- **Actuator:** SG90 servo
- **Signal pin:** D9

**Description**  
The servo actuates the feeder mechanism to release one ping pong ball per `FIRE` command.

---

### 7.4 OLED interface

- **Controller:** Arduino Nano
- **Bus:** I2C
- **Pins:** A4 (SDA), A5 (SCL)

**Description**  
The OLED provides local launcher feedback and configuration display.

---

### 7.5 Potentiometer interface

- **Input pin:** A0
- **Purpose:** local tuning / configuration input

**Description**  
The potentiometer allows local adjustment of launcher settings through the Arduino.

---

### 7.6 Mode button interface

- **Input pin:** D3
- **Purpose:** mode switching

**Description**  
The button is used to toggle or confirm local launcher configuration modes.

---

## 8. Power and Electrical Constraints

### 8.1 Power architecture

| Element | Supply |
|---|---|
| OpenCR | 11.1 V LiPo |
| Raspberry Pi | 5 V from OpenCR |
| Servo | 5 V from Arduino rail |
| OLED | 5 V from Arduino rail |
| Flywheel motor | 6 V rail from buck converter connected to OpenCR 12V|

### 8.2 Grounding

All launcher electronics share a **common ground**, including:
- Arduino Nano
- MOSFET stage
- servo
- OLED
- motor supply return
- Raspberry Pi serial ground

### 8.3 Voltage conversion

The flywheel motor does not run directly from the OpenCR output. A separate 9V battery is stepped down through a micro buck converter to a regulated 6 V motor rail.

---

## 9. Operational Rules

- The **FSM** runs continuously throughout the mission.
- The **camera feed / detection pipeline** runs continuously.
- Other task nodes act only when the current `/states` value matches their function.
- The **remote PC** is required for the full mission because the FSM and main autonomy logic run there.
- The Raspberry Pi and remote PC communicate over the same ROS domain through Wi-Fi.

---

## 10. Out of Scope

This ICD intentionally excludes detailed interfaces for:
- Nav2
- Cartographer
- TurtleBot internal drivers
- OpenCR low-level robot control
- standard ROS 2 middleware internals

These are treated as platform dependencies rather than project-defined subsystem interfaces.

---

## 11. Assumptions

- ArUco detection is performed on the remote PC due to computational load.
- Launcher shot timing is controlled by the Raspberry Pi.
- The Arduino Nano performs only low-level launcher actuation and status reporting.
- All ROS messages and interfaces used are standard ROS 2 types.

---

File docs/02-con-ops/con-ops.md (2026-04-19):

# Concept of Operations
---

## 1. Mission Overview

Group 5's AMR system autonomously navigates an unknown maze-like warehouse environment, builds a map via SLAM, detects ArUco fiducial markers, and delivers ping pong balls to two delivery stations without human teleoperation.

| Station | Task | Type |
|---|---|---|
| **Station A** | Dispense 3 balls into a fixed receptacle on a timed sequence | Primary |
| **Station B** | Dispense 3 balls onto a motorised, oscillating receptacle tracked via ArUco | Primary |

---

## 3. System Architecture

The system is divided into three subsystems coordinated by a central FSM node.

| Subsystem | Key Components | Reference |
|---|---|---|
| Navigation | LDS-02 LiDAR, SLAM Toolbox, Nav2, frontier exploration | [Hardware Docs][hw] · [Software Docs][sw] |
| Perception & Docking | RPi Camera V2, OpenCV ArUco, ROS 2 TF2, LDS-02 LIDAR (final approach) | [Software Docs][sw] |
| Actuation | 130DC flywheel, SG90 servo gate, Arduino Nano | [Hardware Docs][hw] · [Electronics Docs][elec] |

Processing is split between the **Turtlebot SBC** (SLAM, motor control) and the **remote PC** (ArUco detection, PnP pose estimation) to preserve compute headroom for navigation.

For full architecture detail, see the [System Architecture docs][arch].

---

## 4. Mission Flow

### Phase 1 — Explore
The robot autonomously explores the maze using frontier-based exploration via Nav2, targeting ≥ 80% map coverage. Simultaneously, the `aruco_detector2` node monitors the TF tree for valid marker detections (IDs 1 and 2).

### Phase 2 — Dock
On detecting a marker within range, the FSM transitions to `DOCK_{id}`. The docking node executes a three-phase approach: (1) odom dead-reckoning to a standoff point 45 cm along the marker's normal, (2) TF-based fine approach with EMA-filtered pose corrections down to 40 cm, blending bearing and heading alignment, and (3) LIDAR final approach at 1 cm/s to 20 cm from the surface. If the marker is lost during fine approach, a 360° recovery spin searches for re-acquisition. Up to 2 retry attempts are permitted before the marker is skipped and exploration resumes.

### Phase 3 — Static Launch (Station A)
The flywheel spins to steady-state and the SG90 servo gate releases 3 balls sequentially per the team-specific timing sequence. On completion, the FSM returns to explore.

### Phase 4 — Dynamic Launch (Station B)
The ArUco marker on the moving receptacle is tracked continuously. The servo gate is timed to intercept the target based on predicted position. On completion, the primary mission ends.

---

## 5. FSM State Reference

| State | Entry | Exit |
|---|---|---|
| `EXPLORE` | Startup / after delivery / on error | Marker in dock range |
| `DOCK_{id}` | Marker within range | `DOCK_DONE` |
| `STATIC_LAUNCH` | Marker 1 (Static) docked | `LAUNCH_DONE` |
| `DYNAMIC_LAUNCH` | Marker 2 (Dynamic) docked | `LAUNCH_DONE` |
| `END` | Both stations complete | Terminal |

**Topics:** publishes `/states` (`std_msgs/String`), subscribes `/operation_status` (`std_msgs/String`).

**Error handling:** `DOCK_FAIL` retries up to 2× then skips; `NAV_FAIL`, `MARKER_LOST`, `TIMEOUT` all return to `EXPLORE`; `LAUNCH_FAIL` retries the launch sequence.

For the full FSM implementation, see the [Software Docs][sw].

---

## 6. Key Design Choices

| Subsystem | Choice | Rejected Alternatives |
|---|---|---|
| Navigation | Nav2 + SLAM Toolbox + frontier exploration | Custom A* |
| Marker detection | ArUco 4×4_50, PnP pose via OpenCV | Optical flow, LiDAR tracking |
| Docking | Three-phase approach: odom dead-reckoning → TF fine approach with EMA filtering → LIDAR final (1 cm/s) | Pure visual servoing, Nav2 goal-based docking |
| Launcher | Dual 130DC flywheel + SG90 servo gate | Solenoid (~6.6% efficiency), CAM-spring |
| Ball storage | Gravity-fed aluminium ramp (6× 250 mm tubes) | — |

---

## 7. Links

[hw]: ../04-subsystem-design/hardware.md
[elec]: ../04-subsystem-design/electronics.md
[sw]: ../04-subsystem-design/software.md
[arch]: ../03-high-level-design/system-architecture.md

- [Hardware Documentation][hw]
- [Electronics Documentation][elec]
- [Software Documentation][sw]
- [System Architecture][arch]
- [End-User Documentation](../../end-user-docs/end_user_doc_group5.pdf)

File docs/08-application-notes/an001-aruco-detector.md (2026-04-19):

# Application Note — ArUco Marker Detection
AN-001 | v1.0 | 2026-04-05

## Purpose
Documents how ArUco marker detection is configured on the TurtleBot,
including camera calibration, detection parameters, and known limitations.

## Hardware
- Raspberry Pi Camera V2, 8MP
- Mounted 150mm from ground, 0° tilt, forward-facing

## How it works
ArUco markers are detected using the `aruco_detector` ROS2 package. The node
subscribes to `/camera/image_raw/compressed`, runs detection on received frames at a fixed frequency, and publishes
the detected marker pose as a new link to the TF transform tree.

## Camera Calibration
The camera is calibrated to a resolution of 320x240p. The camera intrinisics matrix is defined as a numpy matrix in the source code:

```python
# REMOTE PC!
# ~/turtlebot3_ws/src/auto_nav/auto_nav/aruco_detector2.py

# ...
self.camera_matrix = np.array([
    [635.210233, 0.0, 396.543658],
    [0.0, 635.546243, 304.303293],
    [0.0, 0.0, 1.0]
], dtype=np.float64)
        
self.dist_coeffs = np.array(
    [0.166921, -0.270836, 0.001464, 0.000397, 0.0],
    dtype=np.float64)
```

## ROS2 Parameters
| Parameter | Default | Notes |
|---|---|---|
| `verbose` | `False` | Enable/disable logger for debugging |
| `marker_size` | 0.05 | Physical marker size in metres |
| `frequency` | 20 | Detection timer rate in Hz |
| `benchmark` | `False` | Logs per-frame detection and solvePnP timings in ms |

## Camera startup parameters

The camera node is launched from the ROS bring-up script located at:

```bash
# RPI
~/turtlebot3_ws/src/turtlebot3/launch/bringup/turtlebot3.bringup.py
```
| Parameter | Value |
|---|---|
| `format` | `YUYV` | 
| `height` | 240  | 
| `width` | 320 | 

The 320x240 resolution is chosen to reduce the file size of transmitted images over the ROS topic, lowering bandwidth usage between the RPi and the remote PC.

## Output

When aruco markers are detected, the `aruco_detector` node publishes a new link in the TF tree with the name `aruco_marker_{id}`. The parent link is `camera_optical_frame`. 

## Intermediate link definition

The translation and rotation matrices caculated by OpenCV's `solvePnP()` is with respect to the image coordinate system, which is different from the coordinate system used by the turtlebot.

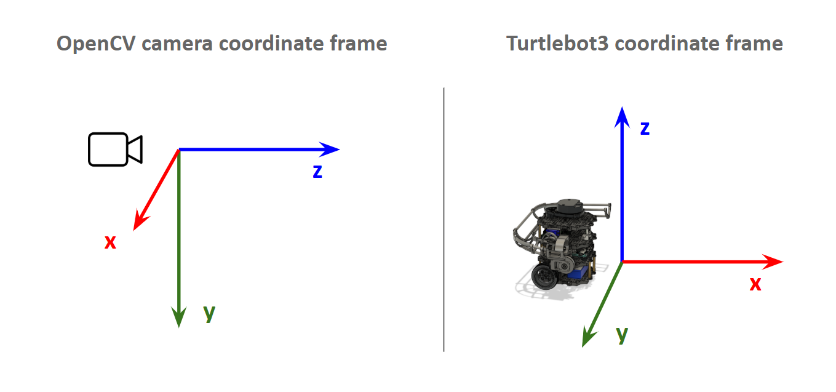
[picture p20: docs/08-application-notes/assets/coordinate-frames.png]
coordinate-frames


Hence, an intermediate link `camera_optical_link` is defined to transform the aruco pose to the turtlebot's coordinate system.

By observation, we can transform the OpenCV camera frame to the Turtlebot3 coordinate frame by:
1) Rotating 90° counter-clockwise about the y-axis,
2) Rotating 90° clockwise about the new x-axis,
3) And finally inverting the z-axis.

The `camera_optical_link` is defined by publishing a static transform to the TF tree with `base_link` as the parent and the above rotation matrix applied during ROS2 Bringup.

## Performance Envelope
Reliable detection: 0.3m – 1.2m, ±30° off-axis (camera FOV ~60°).

Degrades beyond 1.2m under arena fluorescent lighting.

## Caveats
- Marker pose estimation is quite accurate if calibration is done properly and aruco markers are dimensionally accurate. However, the estimated z-distance is the most unrealiable, hence LIDAR data is used in conjunction for accuracy.
- Glossy paper causes specular reflection — use matte print
- Unreliable detection if marker is more than 45° off-axis

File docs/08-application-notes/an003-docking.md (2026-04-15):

# Application Note — Marker Detection and Docking
AN-003 | v0.2.0 | 2026-04-15

## Purpose

This application note describes how ArUco markers are detected and how the
robot performs precision docking in front of a marker. It is aimed at
anyone maintaining or re-tuning the vision and docking subsystems
(`aruco_detector2.py` and `docking.py`) during integration, arena
tuning, or field debugging.

---

## Overview

Markers are detected on the remote PC by `aruco_detector2.py` using
OpenCV's `cv2.aruco` module against the **`DICT_4X4_50`** dictionary.
Each detected marker is pose-estimated with `cv2.solvePnP` using the
`SOLVEPNP_IPPE_SQUARE` solver and broadcast onto the TF tree as
`aruco_marker_<id>` (parent frame: `camera_optical_frame`). Every
downstream consumer — the FSM, the explorer, the docking controller,
and the dynamic launcher — reads markers from TF rather than a
dedicated pose topic.

Docking itself is executed by `docking.py`, which runs a **three-phase
pipeline** driven by a 10 Hz timer:

1. **Phase 1 — Odometry navigation** to a standoff point 45 cm in
   front of the marker along its normal.
2. **Phase 2 — TF-based fine approach** with EMA smoothing, closing
   from 45 cm to 40 cm while blending bearing and heading corrections.
3. **Phase 3 — LIDAR final approach** at constant 1 cm/s to the
   20 cm standoff distance.

The docking node is triggered by `DOCK_<id>` on `/states` and reports
the outcome (`DOCK_DONE` / `DOCK_FAIL` / `TIMEOUT`) on
`/operation_status`.

---

## Camera Setup

- **Camera:** Raspberry Pi Camera V2, mounted forward-facing on the
  turret plate.
- **Stream:** `/camera/image_raw/compressed` (`sensor_msgs/CompressedImage`),
  subscribed with BEST_EFFORT QoS.
- **Intrinsics:** hard-coded inside `aruco_detector2.py`
  (`camera_matrix` and `dist_coeffs`). The commented-out
  `np.load(... camera_calib.npz)` path shows where a calibration file
  *would* be loaded if re-enabled. If you re-calibrate the camera
  with `camera_calibration` or a checkerboard script, update these
  arrays or switch the loader back on.
- **Published frame:** all marker transforms are broadcast with parent
  `camera_optical_frame` — ensure that frame is actually published by
  your camera driver's static TF.

---

## Marker Configuration

- **Dictionary:** `cv2.aruco.DICT_4X4_50`
- **Default physical size:** 0.05 m (5 cm, set via the `marker_size`
  ROS 2 parameter — overridable at launch time)
- **Print requirements:** matte/non-glossy paper, dictionary-accurate,
  mounted flat. The **printed side length must match** `marker_size`
  exactly or PnP will produce a biased range.

| Station | Marker ID | Physical Size |
|---|---|---|
| Station A (static launch) | 1 | 5 cm |
| Station B (dynamic launch) | 2 | 5 cm |
| Lift lobby (bonus) | 3 | 5 cm |

The FSM ignores marker 3 until markers 1 and 2 have been completed.

---

## Key Parameters

### Detection (`aruco_detector2.py`)

| Parameter | Default | Notes |
|---|---|---|
| `frequency` | 20 Hz | Detection timer rate. |
| `marker_size` | 0.05 m | Must match the printed side length. |
| `verbose` | `False` | Per-marker INFO logging. |
| `benchmark` | `False` | Logs detection + `solvePnP` timings. |

### Docking (`docking.py`)

| Parameter | Default | Notes |
|---|---|---|
| `nav_standoff` | 0.45 m | Phase 1 goal distance along marker normal. |
| `fine_approach_dist` | 0.40 m | Phase 2 stopping distance (TF). |
| `standoff_distance` | 0.20 m | Phase 3 stopping distance (LIDAR). |
| `odom_position_tol` | 0.05 m | Phase 1 arrival tolerance. |
| `lateral_tol` | 0.03 m | Phase 2 lateral alignment tolerance. |
| `distance_tol` | 0.03 m | Phase 2 distance tolerance. |
| `final_tol` | 0.03 m | Phase 3 LIDAR distance tolerance. |
| `heading_tol` | 0.05 rad | Angular tolerance for heading alignment. |
| `angular_threshold` | 0.05 rad | Threshold to trigger pure rotation (vs. blended). |
| `k_linear` / `k_angular` | 0.5 / 1.0 | P-control gains. |
| `lpf_alpha` | 0.35 | EMA factor for position/normal smoothing (Phase 2). |
| `max_linear` / `max_angular` | 0.10 m/s / 0.05 rad/s | Velocity limits. |
| `min_angular` | 0.01 rad/s | Rotation deadband floor (stiction). |
| `recovery_spin_speed` | 0.1 rad/s | Phase 2 360° search spin speed. |
| `lidar_arc_deg` | 3.0° | Half-arc sampled around 0 rad for range. |
| `phase1_timeout_sec` | 40 s | Abort Phase 1 if not reached in time. |
| `timeout_sec` | 120 s | Global safety timeout across all phases. |

All of the above are declared as ROS 2 parameters and can be
overridden at launch (e.g. `ros2 run auto_nav docking --ros-args -p
nav_standoff:=0.5`).

---

## Docking Approach

The full sequence, as implemented in `docking.py`:

1. **Trigger** — `fsm_controller.py` publishes `DOCK_<id>` on
   `/states`. The docking node resets all state, creates a 10 Hz
   timer, and enters Phase 1.
2. **Phase 1 (odom nav to standoff)** — on the first iteration a
   single TF lookup (`aruco_marker_<id>` in `base_link`) is used to
   extract the marker's position and rotation-matrix Z-column normal
   (projected to XY and flipped toward the robot with a dot-product
   stability check to reject sudden 180° flips). A goal point
   `nav_standoff` metres in front of the marker, plus the heading to
   face it, are projected into `odom`. The robot then drives toward
   the goal with P-control; when at the goal it rotates to face the
   marker.
3. **Phase 2 (TF fine approach)** — the marker is re-acquired every
   tick via TF. Position and normal are passed through an exponential
   moving average (α = 0.35). If the marker is off-centre by more than
   `angular_threshold`, the robot does a pure rotation to centre it.
   Otherwise forward motion plus a **blended angular command** is
   issued: (1 − blend)·bearing + blend·heading-alignment, where
   `blend` ramps from 0 at the standoff to 1 at `fine_approach_dist`.
   Near the target, angular output is damped by 0.3 to prevent
   oscillation. The phase completes when lateral error < 3 cm AND
   distance error < 3 cm for **5 consecutive ticks (0.5 s)**.
4. **Phase 3 (LIDAR final)** — heading is trusted from Phase 2. Only
   LIDAR is used for range (a 3° half-arc centred on 0 rad). The robot
   drives forward/backward at ±1 cm/s until within `final_tol` of the
   20 cm standoff, then publishes `DOCK_DONE`.

### Failure modes

| Condition | Behaviour |
|---|---|
| Marker TF lost in Phase 2 for ~2 s (20 consecutive misses) | 360° recovery spin at 0.1 rad/s; if re-acquired, resume fine approach; otherwise publish `DOCK_FAIL`. |
| Phase 1 doesn't reach standoff within `phase1_timeout_sec` (40 s) | Publish `TIMEOUT`. |
| Any phase stalls for more than `timeout_sec` (120 s) | Publish `TIMEOUT`. |
| `odom → base_link` TF fails 50× in a row | Publish `DOCK_FAIL`. |
| Marker TF fails 50× in a row during Phase 1 goal computation | Publish `DOCK_FAIL`. |

### FSM-level retry

On `DOCK_FAIL`, `fsm_controller.py` retries docking once. A second
consecutive failure adds the marker to the completed-set (so it is
never re-selected) and returns the robot to `EXPLORE`.

---

## Performance Envelope

- **Reliable detection range:** roughly 0.3–3.0 m with the default
  5 cm marker and onboard intrinsics. Detections below ~20 cm suffer
  from the camera's minimum focus distance.
- **Off-axis tolerance:** tested up to ~±45° off the marker normal.
  Beyond that, `solvePnP` pose can flip and is rejected by the normal
  dot-product check, causing brief TF dropouts.
- **Lighting:** works best in diffuse indoor lighting. Direct
  glare/reflections on glossy prints are the most common failure
  mode.
- **Docking final pose:** typically 20 cm ± 3 cm LIDAR range, with
  lateral error ≤ 3 cm and heading error well within 0.05 rad after
  Phase 2.

---

## Known Limitations

| Issue | Impact | Mitigation |
|---|---|---|
| Intrinsics are hard-coded; re-calibration requires editing `aruco_detector2.py`. | Incorrect range/heading if the camera is swapped. | Re-enable the `camera_calib.npz` loader or patch the matrix in source. |
| Single TF lookup at the start of Phase 1 — no cross-check. | A noisy first reading biases the whole Phase 1 goal. | Stay stationary and face the marker for ~1 s before issuing `DOCK_<id>`. |
| Phase 3 uses a fixed 1 cm/s approach, so reaching the 20 cm standoff can be slow. | Adds a few seconds to docking. | Increase the constant in `_phase_lidar_final` if needed, but verify bumpless stop. |
| Marker flips (180°) around ±45° off-axis. | Momentary wrong-direction goal. | Normal-flip rejection is already in place; keep the approach roughly head-on. |
| `camera_optical_frame` must be published by the camera driver. | Missing TF → no detections ever. | Verify `ros2 run tf2_ros tf2_echo camera_optical_frame base_link` resolves. |

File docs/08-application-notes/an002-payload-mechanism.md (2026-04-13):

# Application Note - Payload Launch Mechanism
AN-002 | v1.0 | 2026-04-13

## Purpose

Documents the serial command interface, electrical connections, and operational
constraints for the G2 ping pong ball launcher, for integration with the RPi
ROS2 software stack.

---

## Overview

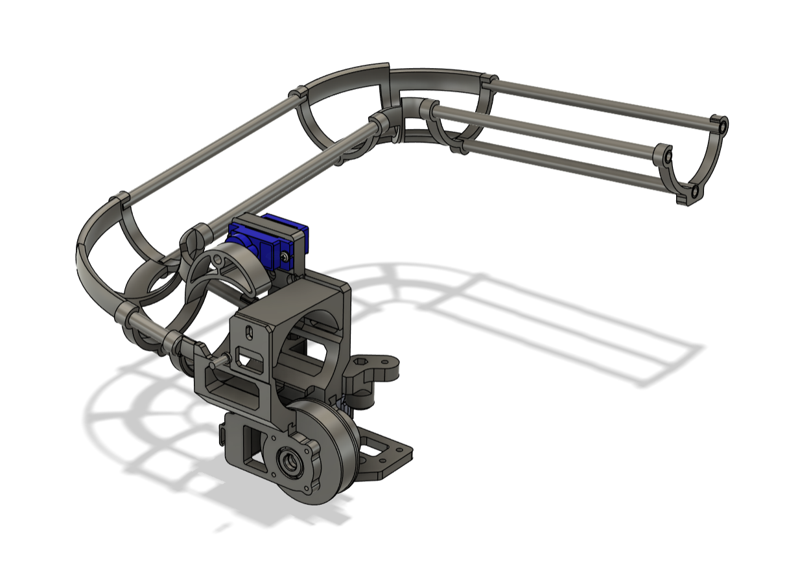
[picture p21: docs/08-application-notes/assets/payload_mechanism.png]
payload-mechanism


The launcher is a self-contained subsystem controlled by a dedicated Arduino Nano
launcher controller. The RPi issues high-level ASCII commands over USB serial -
the controller handles all timing, servo sequencing, and flywheel management
internally.

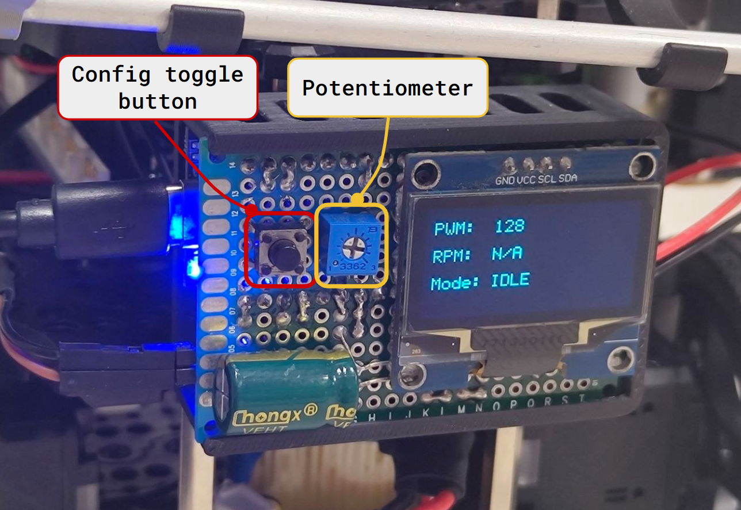
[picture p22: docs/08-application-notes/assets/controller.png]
launcher_controller

---

## Serial Command Interface

**Connection:** USB serial, `/dev/ttyUSB0` (see note below), 115200 baud

| Command | Description | Response |
|---|---|---|
| `PING` | Connection health check | `PONG` |
| `SPIN` | Start flywheel | none |
| `FIRE` | Feed one ball through the indexer | none |
| `STOP` | Stop flywheel | none|
| `SLAUNCH` | Full static delivery sequence (Station A) | none |
| `DLAUNCH` | Full dynamic delivery sequence (Station B) | none |

> **Port assignment:** Confirm the port with `ls /dev/ttyUSB*` before launch. To
> prevent the port changing between reboots, create a udev rule binding the
> Arduino's USB ID to a fixed symlink `/dev/arduino-launcher`.

### Example RPi Python usage

```python
import serial, time

ser = serial.Serial('/dev/ttyUSB0', 115200, timeout=1)
time.sleep(2)  # wait for Arduino reset on serial open

ser.write(b'PING\n')
assert ser.readline().decode().strip() == 'PONG', "Launcher not responding"

ser.write(b'SPIN\n')
time.sleep(2)
ser.write(b'FIRE\n')
time.sleep(2)
ser.write(b'STOP\n')
```

---

## Power Rails

| Rail | Source | Relevant to |
|---|---|---|
| +6V | Buck converter (from OpenCR 12V) | Flywheel motor |
| +5V | Arduino Nano onboard regulator | Servo, OLED |

Do not command `SPIN` or `SLAUNCH` / `DLAUNCH` while the robot is actively
navigating - motor spin-up draws ~800mA peak on the +6V rail and may cause
voltage sag affecting the OpenCR board.

---

## Controller schematic

controller-schematic

---

## Pin Assignment

| Arduino Pin | Signal | Connected to |
|---|---|---|
| D3 | `BUTTON` | Config push button |
| D6 | `SERVO_SIG` | SG90 servo PWM |
| D9 | `MOTOR_SIG` | IRLZ44N gate (flywheel PWM) |
| A0 | `POT_SIG` | Speed potentiometer |
| A4 / A5 | `SDA` / `SCL` | OLED I2C |

---

## Timing Constraints

- The Arduino resets when the RPi opens the serial port - allow **2 seconds**
  before sending any command
- If using `SPIN` + `FIRE` manually, allow **~2 seconds** of spin-up before
  issuing `FIRE` - the feeder servo needs time to reset and load next ball.
- `SLAUNCH` and `DLAUNCH` handle spin-up internally; do not prepend a manual
  `SPIN` call when using these commands
- Optimal docking distance for consistent delivery is **100–150mm** from the
  receptacle.

---

## On-Robot Speed Tuning (Config Mode)

Motor speed can be adjusted without reflashing firmware:

1. Press the config button - OLED displays current PWM value
2. Turn the potentiometer to adjust speed
3. Press again to save PWM (temporary, resets to default of 128 on reboot)

---

## Known Limitations

| Issue | Impact | Mitigation |
|---|---|---|
| Serial open resets Arduino | ~2s unavailable on startup | Always `PING` before first fire command |
| Motor spin-up current draw | Potential voltage sag on +6V rail | Do not launch during active navigation |
| Indexer gate misalignment | Ball jam | Physically check gate alignment before mission |
| Servo jitter due to EMI | Ball feeding sequence may fail if jitter is significant | Avoid running motor on full RPM to reduce EMI |

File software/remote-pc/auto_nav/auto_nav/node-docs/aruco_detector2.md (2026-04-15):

# ArUco Detector (`aruco_detector2.py`)

`aruco_detector2.py` is the perception node for marker detection. It
subscribes to `/camera/image_raw/compressed` (`sensor_msgs/CompressedImage`)
with a BEST_EFFORT QoS, decodes each frame to BGR, and caches a
grayscale snapshot in an internal buffer. At a configurable frequency
(default 20 Hz) a timer callback runs
`cv2.aruco.detectMarkers` on the latest frame using the `DICT_4X4_50`
dictionary. For every detected marker it solves `cv2.solvePnP`
(`SOLVEPNP_IPPE_SQUARE`) against hard-coded camera intrinsics and the
configured `marker_size` (default 5 cm) to recover pose, converts the
rotation vector to a quaternion, and broadcasts it on TF as
`aruco_marker_<id>` with parent frame `camera_optical_frame`. The node
exposes `verbose`, `frequency`, `marker_size`, and `benchmark`
parameters for runtime tuning.

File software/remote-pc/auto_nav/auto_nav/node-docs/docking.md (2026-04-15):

# Docking

## Three-Phase Autonomous Docking

Docking is handled by `docking.py`, which navigates the TurtleBot3
into alignment in front of an ArUco marker pasted next to the target
receptacle. The node is triggered by a `DOCK_<id>` message on
`/states` and reports the outcome (`DOCK_DONE`, `DOCK_FAIL`, or
`TIMEOUT`) on `/operation_status`. It runs a 10 Hz control loop and
sequences three phases.

**Phase 1 — Odometry Navigation to Standoff (45 cm along the marker
normal)**
On receiving a dock command, the node performs a single TF lookup of
`aruco_marker_<id>` in the `base_link` frame, extracts the marker
normal from the rotation matrix (projected to XY, flipped to point
toward the robot), and computes a standoff goal `nav_standoff` metres
(default 0.45 m) in front of the marker along that normal. The goal is
then converted to the `odom` frame and driven to with P-control on
translation and heading. Position tolerance is 5 cm; on arrival the
robot rotates to face the marker. A 40 s Phase-1 timeout aborts the
attempt if the standoff cannot be reached.

**Phase 2 — TF-Based Fine Approach (45 cm → 40 cm)**
The node re-acquires the marker via TF with an exponential moving
average (α = 0.35) applied to both position and normal. Angular
control blends a bearing correction (keep marker centred) at distance
with heading alignment (face the marker's normal) up close. The phase
completes once the robot holds both lateral alignment within 3 cm and
distance error within 3 cm for five consecutive ticks (0.5 s). If the
marker is lost for more than ~2 s, a 360° recovery spin at 0.1 rad/s
is performed while polling TF; if the marker is re-acquired the fine
approach resumes, otherwise `DOCK_FAIL` is published.

**Phase 3 — LIDAR Final Approach (to 20 cm)**
Heading is already aligned from Phase 2's blended angular control, so
Phase 3 uses only forward LIDAR (a 3° half-arc centred on 0 rad) for
distance measurement and drives at a constant 1 cm/s until within the
3 cm final tolerance of the 20 cm standoff distance, then publishes
`DOCK_DONE`.

A 120 s global safety timer aborts the sequence if it stalls, and the
node will also bail out with `DOCK_FAIL` if either the odom TF or the
marker TF lookup fails 50 times in a row.

**Flowchart**
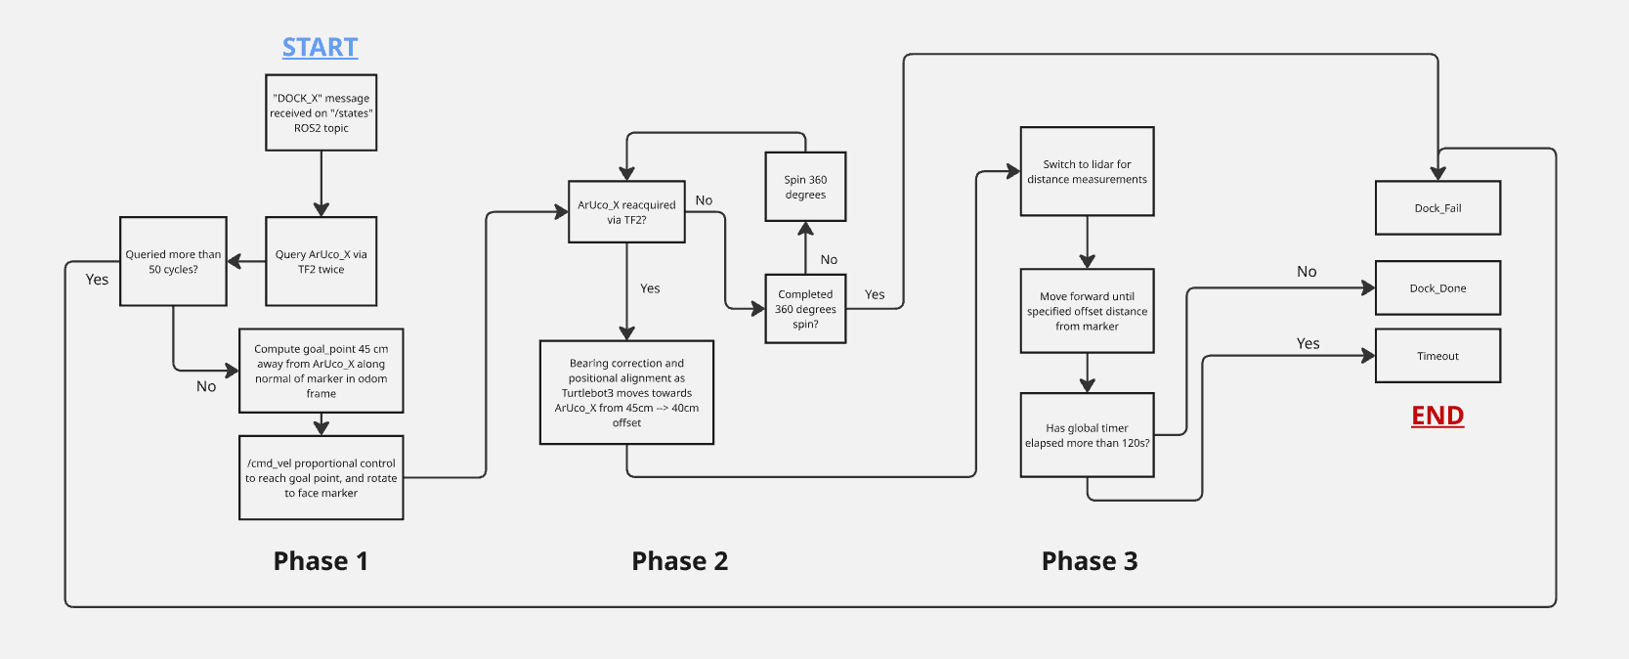
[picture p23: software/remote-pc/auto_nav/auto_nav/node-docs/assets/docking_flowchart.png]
Docking Flowchart


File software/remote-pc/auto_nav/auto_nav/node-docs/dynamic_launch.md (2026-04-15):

# Dynamic Launcher (`dynamic_launch.py`)

`dynamic_launch.py` runs on the remote PC and owns all launcher
sequencing logic. It subscribes to `/states` and activates in one of
two modes: `STATIC_LAUNCH` (fires 3 balls with a 5.5 s cooldown after
a brief spin-up) or `DYNAMIC_LAUNCH` (polls TF at 10 Hz for
`aruco_marker_<target_marker_id>`, and when a **fresh** transform is
available — `header.stamp` age ≤ 0.2 s — waits `launch_delay` seconds,
re-checks freshness, then fires one ball; repeats until `max_shots`
shots have been taken, subject to `shot_cooldown`). Launcher primitives
(`SPIN`, `FIRE`, `STOP`) are published on `/arduino_cmd`, which an RPi
bridge node forwards over serial to the Arduino; the Arduino's raw
replies return on `/arduino_response` for logging. Completion is
reported on `/operation_status` as `LAUNCH_DONE`, `LAUNCH_TIMEOUT`
(no shot fired before `node_timeout`, default 30 s), or
`LAUNCH_INCOMPLETE` (timeout after a partial sequence).

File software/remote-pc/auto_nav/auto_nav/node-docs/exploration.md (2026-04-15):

## Autonomous Exploration

### SLAM and Navigation2
In this project, SLAM is implemented on top of ROS 2 on the TurtleBot3 platform. The TurtleBot3 is equipped with a 2D LiDAR sensor, wheel encoders, and an onboard IMU. These sensors provide laser scan data for obstacle detection and mapping (`/scan`), odometry data for motion estimation (`/odom`), and IMU data for orientation refinement.

The active mapping stack is **Cartographer** (launched via `turtlebot3_cartographer.launch.py`), which performs real-time graph-based SLAM. Robot poses are represented as nodes in a graph and sensor constraints are used to optimise the map, reducing accumulated drift.

After the map is generated, the **Navigation2 (Nav2)** stack handles path planning and obstacle avoidance. Nav2 consumes the live occupancy grid from Cartographer, maintains real-time costmaps, and exposes the `NavigateToPose` action used by this node for all goal dispatch.

### Frontier-Based Exploration
A frontier is the boundary between known free space and unknown space in the occupancy grid. The explorer incrementally drives the robot toward these frontiers until the map is sufficiently complete.

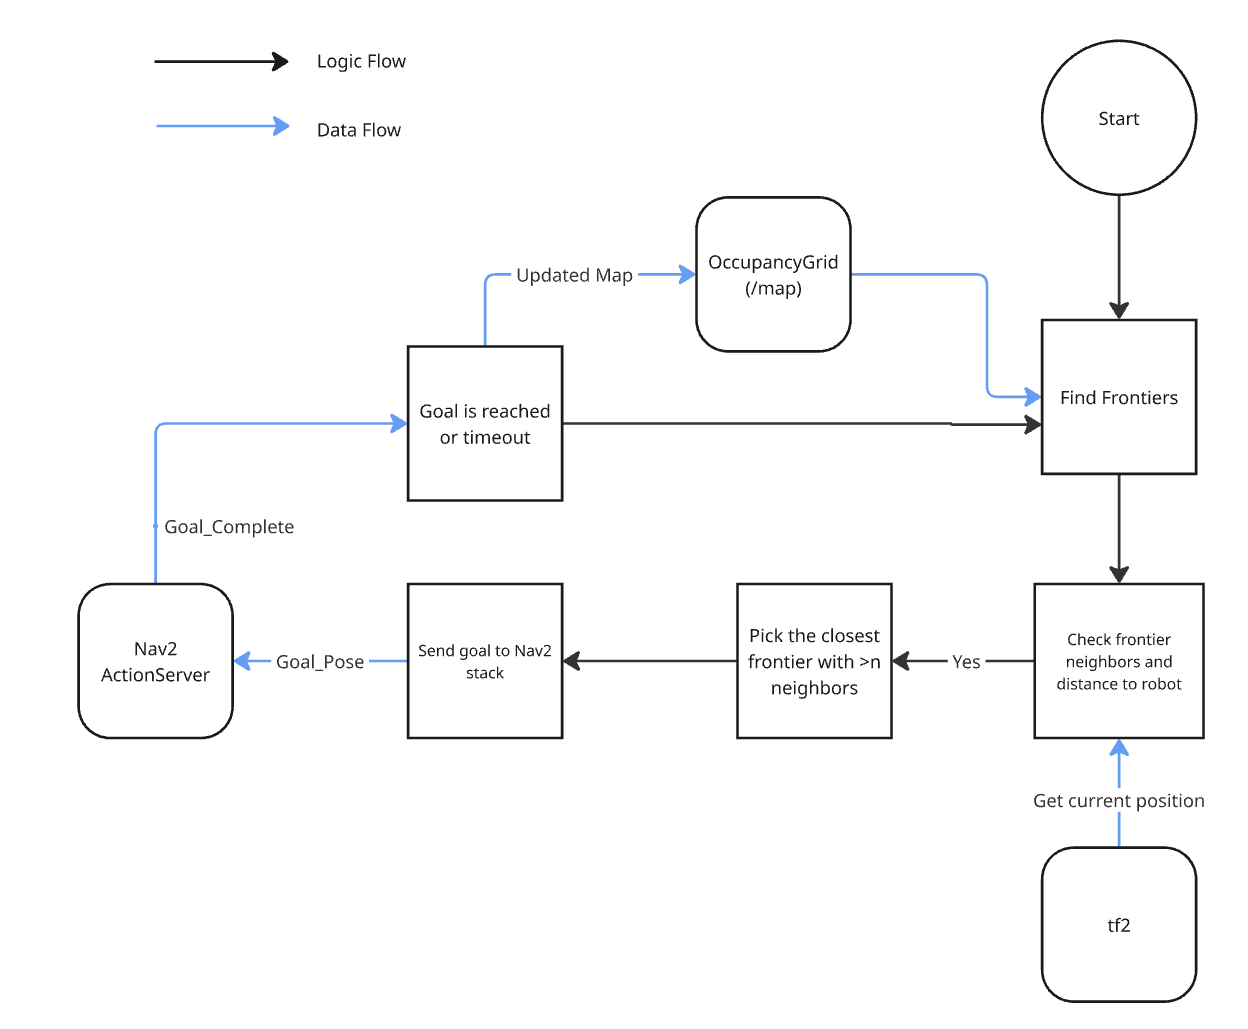
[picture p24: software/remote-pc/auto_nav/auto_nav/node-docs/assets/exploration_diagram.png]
Exploration Diagram


The workflow is as follows:
1. Wait for `EXPLORE` (or `EXPLORE_<id>`) on `/states`.
2. On each `/map` update the occupancy grid is scanned for frontier cells: free cells (value `0..49`) adjacent to an unknown cell (`-1`).
3. Candidate frontiers are filtered: those too close to the robot (<1 m) or too close to walls (<1 cell from any occupied cell, where walls are cells with value ≥ 50) are rejected.
4. For each remaining candidate, the number of nearby frontier neighbours (within 0.5 m) is counted. Frontiers with more than 5 neighbours are kept (this suppresses tiny isolated frontiers).
5. Of the surviving candidates, the one with the **largest distance to the nearest wall** is selected as the navigation goal — this biases exploration away from tight corridors.
6. The goal cell is converted to map coordinates and sent as a `NavigateToPose` goal to Nav2.
7. A new goal is issued once the current one is reached (or after a 10 s timeout if progress stalls).

### Marker storage and marker-directed exploration
Alongside frontier search, the node continuously looks up every
`aruco_marker_<id>` frame it sees in TF (relative to `map`) at 10 Hz
and caches the full pose (position + quaternion). When the FSM
publishes `EXPLORE_<id>` (where `<id>` identifies a marker that is
already catalogued), the explorer switches from pure frontier search
to a directed goal: it reconstructs the marker's facing direction from
its stored orientation, offsets 0.5 m out along that facing direction,
and dispatches a Nav2 goal facing back at the marker. While the marker
is not yet catalogued, normal frontier exploration continues. Any
non-`EXPLORE*` state cancels the current Nav2 goal.

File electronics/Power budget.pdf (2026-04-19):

Component | Voltage (V) | Average current (A) | Uptime (seconds) | Assumptions | Energy used (J)
Turtlebot (bootup) | 11.1V | 0.97 | 60 | - | 646.02
Turtlebot (active navigation) | 11.1V | 1.14 | 1200 | Assuming 20 minutes runtime | 15184.80
Launcher motor (DC 130) | 6V | 0.86 | 70 | Assuming 20 seconds for 2x static stations, and 30 seconds for dynamic | 361.20
SG90 Servo | 5V | 0.12 | 18 | Assuming 2 seconds actuation per ball, for 9 balls | 10.8
Total energy | | | 16202.82 J = 4.50 Wh
Battery rated capacity | | | 19.98 Wh
Battery usable capacity | | | 15.98 Wh (assuming 80% usable)
Margin w.r.t mission requirement | | | 255%
- “Turtlebot” refers to the entire default Turtlebot3 Burger including the Raspberry Pi Camera V2.
- Current measurements are performed by connecting the components to the adjustable power supply and monitoring current draw over time.

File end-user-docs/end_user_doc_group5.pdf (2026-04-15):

END USER DOCUMENTATION
TurtleBot3 | Group 5 | CDE2310

Section 1 – General System Description & Critical Data (Spec Sheet)

Model / Platform | TurtleBot3 Burger (Modified – G5)
Software Version | v1.1.0
ROS Version | ROS 2 Humble
Total Mass | ~1095 g (including launcher assembly)
Centre of Gravity (x, y, z) | (−2.28 mm, −8.18 mm, 71.75 mm) from robot base centre
Battery | LI-PO 11.1V 1800mAH LB-12 19.98Wh 5C
Drive Motors | DYNAMIXEL XL430-W250 × 2
LiDAR | LDS-02 (360°, top-mounted)
Camera | Raspberry Pi Camera Module (forward-facing)
SBC | Raspberry Pi 4
MCU | OpenCR 1.0, Arduino Nano
Flywheel Motor | 130 DC Motor 6V
Mission Time Limit | 25 minutes (includes document check at start)
Operating Environment | Simulated Indoor Warehouse Conditions
Bot Purpose | Autonomous SLAM navigation + ping pong ball delivery to Station A (static ArUco) and Station B (moving ArUco)
Document Version | v1.1
Date of Issue | 14 Apr 2026

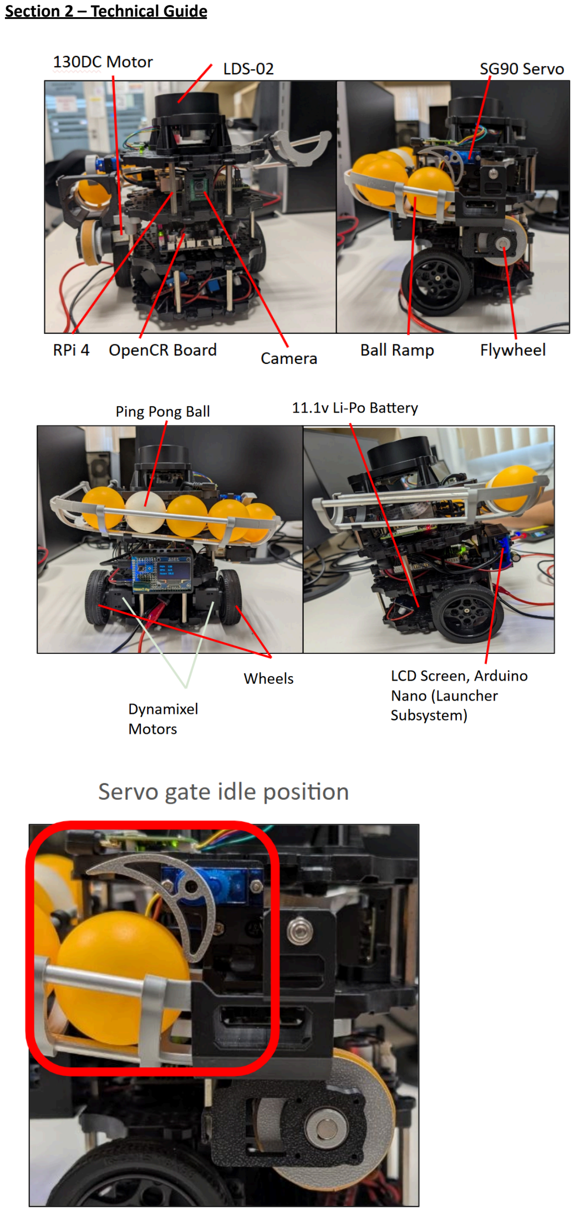
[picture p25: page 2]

Section 2 – Technical Guide

### 2.1 How the TurtleBot3 Accomplishes the Mission

The robot runs ROS 2 Humble on a Raspberry Pi 4 (SBC), which communicates with the OpenCR 1.0 (MCU) over USB. The LDS-02 LiDAR feeds the Nav2 SLAM stack for autonomous mapping and navigation. The forward-facing camera detects ArUco markers to identify and align with delivery stations. The Raspberry Pi commands the launcher controller (Arduino Nano MCU) through USB to dispense ping pong balls on command.

### 2.2 Pre-Mission Start Procedure

# | Step

1 | Charge and verify battery voltage ≥ 10.8 V. Power on robot via OpenCR switch.
2 | Load 6 ping pong balls onto ramp.
3 | Ensure servo gate encapsulates one ping pong ball.
4 | Place the robot at the start position.
5 | Begin screen recording of RViz.
6 | On RPi (SSH) – run: rosbu (Wait till rosbu prints ‘Run!’ on the RPi)
7 | On Remote PC – source workspace, then run: ros2 run auto_nav mainlaunch (on mission start command)
8 | Confirm RViz is visible with active LiDAR scan.

### 2.3 Mission Flow

Step | Phase | Description
1 | Explore & Map | SLAM + frontier search. Target ≥ 80% map coverage. Uses ≤ 6 landmark markers.
2 | Station A | Detect static ArUco. Align within 10 cm. Dispense exactly 3 balls in sequence.
3 | Station B | Differentiate moving vs. static ArUco. Track position. Dispense onto moving target.
4 | Recovery | Nav2 auto re-plans on failure with no human intervention.

### 2.4 Key Software Nodes

Node | Function
exploration2 node | Path planning, obstacle avoidance, recovery behaviours Online SLAM – map generation and localisation
aruco_detector2 node | Marker detection; static vs. dynamic classification
fsm_controller node | Top-level state machine; sequences all tasks autonomously
launcher node | Flywheel speed control and servo gate logic

### 2.5 Launcher Assembly Specs

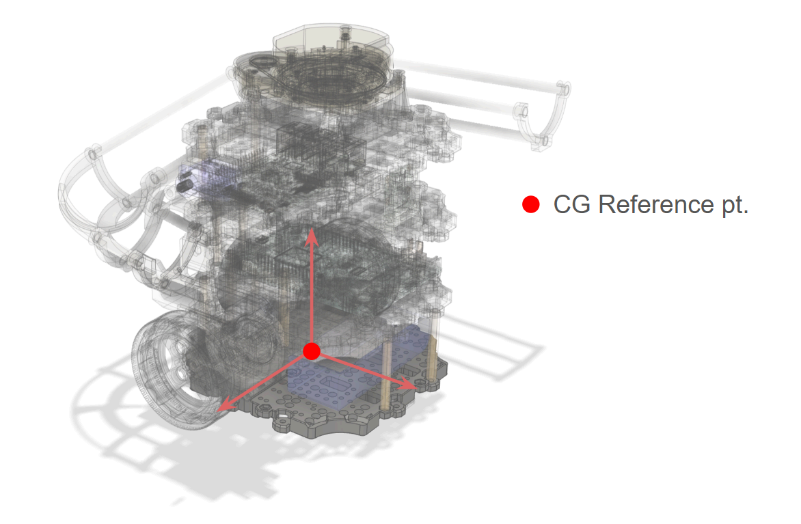
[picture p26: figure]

Component | Detail
Flywheel Motor | 130 DC Motor; driven viaL298N driver; position (−75, 5, 67) mm
Servo Gate | SG90 servo; releases one ball at a time; position (−75, −18, 130) mm
Ramp Guides | 6 mm OD aluminium tubes × 6; length 250 mm each
Motor Driver | L298N Motor driver, powered by 9V Battery
Target Success Rate | ≥ 70% ball dispense accuracy

Section 3 – Acceptable Defect Log
Record defects that are not in perfect condition but still acceptable for mission execution. Must be assessed and signed off by a team member before mission start.
# | Component | Description of Defect | Justification / Mitigation | Assessed By | Date

1 | SG90 Servo | Slight servo jitter, < 5 degrees from nominal position | Servo jitter due to EMI from inrush current during startup. | 3SG Wang yizhang | 14 Apr 2026
2 | Ping pong ball ramp | Guide rods may become disconnected from frame | Rod disconnection does not occur during normal operation; only when the robot is lifted by the ramp. Reinsertion takes <10 seconds and does not affect launcher accuracy | Niki S | 14 Apr 2026

Assessed By: 3SG Gary Chen Date: 14 Apr 2026 Signature: _______________________

Section 4 – Factory Acceptance Test (FAT) Checklist
Complete all checks before the mission run. Part of the 25-minute mission window
Hardware
# | Check Item | P / F

H1 | Battery voltage ≥ 10.8 V before power-on | P / F
H2 | All structural plates securely fastened | P / F
H3 | No loose cables dangling outside of robot chassis | P / F
H4 | DYNAMIXEL motors and wheels rotate freely, with no binding, resistance or obstruction | P / F
H5 | LiDAR spins freely with no jam or abnormal resistance | P / F
H6 | Flywheel and servos launch ping pong balls with no jam or abnormalities Launch command on RPi: rosbu Launch command on Remote PC: ros2 run auto_nav fat_launch | P / F
H7 | ArUco marker detected at 0.5m at maze lighting conditions Launch command on RPi: rosbu Launch command on Remote PC: ros2 run auto_nav fat_aruco | P / F
H8 | Ping pong balls slides smoothly down ramp | P / F
H9 | Servo gate encapsulates 1 ping pong ball in idle position | P / F

Software & Communication

# | Check Item | P / F

S1 | Remote PC ↔ RPi SSH connection established | P / F
S2 | LIDAR data received & plotted in active RViz map after launch | P / F
S3 | No error logs or messages during testing of hardware | P / F
S4 | Ctrl-C terminates all nodes | P / F

FAT Sign-off – Test Conductor: _______________________ Date: _______________________

Section 5 – Maintenance and Part Replacement Log
Record all maintenance and component replacements. This log stays with the robot at all times.

### 5.1 Maintenance Log

# | Date | Component | Action Taken / Part Replaced | Reason | Done By

1 | 14 Apr 2026 | 9V Battery Cell | 9V Battery Added | Isolate Launcher Power Supply | 3SG Gary Chen

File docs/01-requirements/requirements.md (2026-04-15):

# System Requirements

## 1. System Overview

The system is an autonomous mobile robot (AMR) based on the TurtleBot3 platform.  
It is designed to navigate an unknown indoor environment, construct a map, localize itself, and autonomously deliver ping pong balls to designated stations under specified competition constraints.

## 1.1 Functional Requirements (FR)

### Navigation & Mapping
- The system shall autonomously explore and map an unknown environment using SLAM and frontier search algorithms.
- The system shall plan and execute collision-free paths to target locations by varying parameters of Nav2 Stack.

### Station A – Static Delivery
- The system shall detect ArUco markers at Station A.
- The system shall align itself with the receptacle before dispensing.
- The system shall dispense exactly three (3) ping pong balls in sequence.

### Station B – Dynamic Delivery
- The system shall differentiate the static ArUco marker and moving ArUco marker.
- The system shall track the velocity  and position of the moving ArUco marker.
- The system shall dispense ping pong balls onto the moving target.

### Mission Execution
- The system shall execute all tasks autonomously without human intervention after mission start.

### Bonus (Optional)
- The system shall communicate with a lift API to transition between levels.

## 1.2 Performance Requirements

- The system shall be capable of recovering from minor navigation failures (e.g., re-planning paths).
- The robot shall align with delivery receptacles with a positional error of no more than 10 cm.

## 1.3 Constraint Requirements

- The system shall complete the mission within 25 minutes.
- The system shall not use line-following techniques.
- The system shall operate fully autonomously after mission start.
- The system shall use no more than six (6) landmark markers.
- No teleoperation once the mission clock starts

## 1.4 Reliability Requirements
- The ball dispensing success rate shall be at least 70%.
- The exploration algorithm should explore at least 80% of the unkwown environment 90% of the time.

## 1.5 Interface Requirements

- The mission manager will ideally type one command on both the remote_pc and rpi to start all nodes.
- RViz map screen recording interface should always be present.

## 1.6 Operating Environments

- The Walls shall be tall enough for the lidar to detect them.
- The ArUco smarkers shall be well-lit for the cameras to detect them.
- The robot shall operate in an indoor warehouse-like environment with a maze configuration.

## 1.7 Safety Requirements

- The robot shall be caught if robot starts damaging the maze.
- The system may be interupted/terminated with ctrl-c

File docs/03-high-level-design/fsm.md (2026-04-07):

# Finite State Machine (FSM)

## Overview

The system is controlled using a Finite State Machine (FSM) implemented in the `fsm_controller` node.

The FSM coordinates navigation, perception (ArUco detection), docking, and launching subsystems to execute the mission autonomously. Communication between subsystems is centralized via a unified `/operation_status` topic.

Unlike a fixed-state FSM (e.g., DOCK_A, DOCK_B), this implementation dynamically handles multiple markers using marker IDs (e.g., `DOCK_3`, `LAUNCH_3`).

---

## FSM Diagram
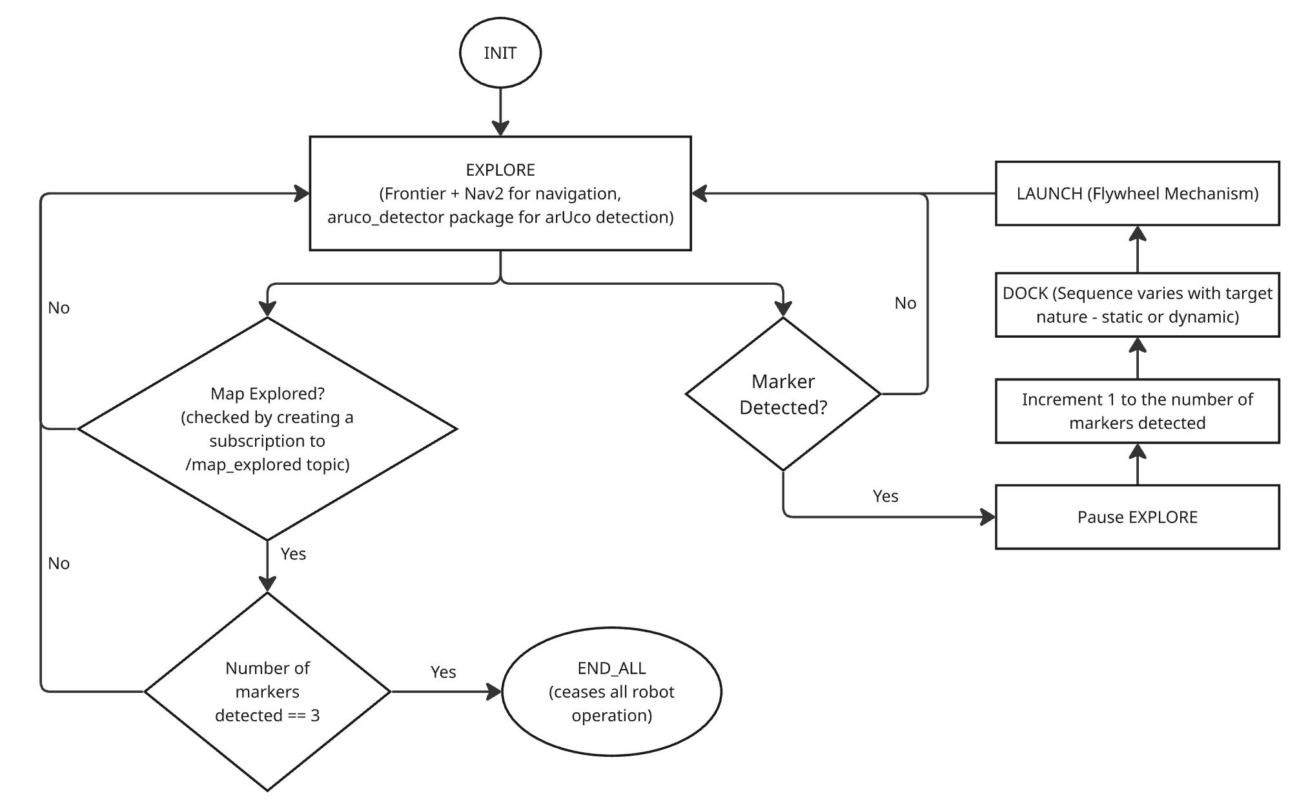
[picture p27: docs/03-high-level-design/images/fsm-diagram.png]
fsm-diagram


---

## State Definitions

### INIT
System startup and initialization of all ROS2 nodes.

---

### EXPLORE
Robot performs exploration (e.g., frontier-based with Nav2) while searching for ArUco markers.

- Subscribes to `/aruco_pose`
- Detects markers and extracts marker ID
- Publishes marker ID on `/current_marker`
- Transitions to docking when a marker is detected

---

### DOCK_<marker_id>
Robot docks at the detected station using the ArUco marker.

- Triggered dynamically (e.g., `DOCK_3`, `DOCK_5`)
- Docking handled by `docking_node`
- Uses TF + LIDAR-based multi-phase docking
- FSM tracks docking attempts for fault tolerance

---

### LAUNCH_<marker_id>
Robot performs payload delivery (e.g., launching ping pong balls).

- Triggered after docking completes or times out
- Marker ID is preserved (e.g., `LAUNCH_3`)
- On completion, increments delivered marker count

---

### END
Mission complete. Robot stops all operations.

---

## State Transitions

### Normal Operation

- INIT → EXPLORE (after initialization)
- EXPLORE → DOCK_<id> (when marker is detected)
- DOCK_<id> → LAUNCH_<id> (on `DOCK_DONE`)
- LAUNCH_<id> → EXPLORE (on `LAUNCH_DONE`)
- EXPLORE → END (when map explored AND required markers completed)

---

### Error Handling & Recovery

The FSM incorporates fault handling using `/operation_status`.

#### Docking Failures
- `DOCK_FAIL`:
  - Retry docking **once**
  - If failure occurs twice → transition to `END`

#### Docking Timeout
- `TIMEOUT`:
  - Assumed robot is sufficiently aligned
  - FSM proceeds directly to `LAUNCH_<id>`

#### Navigation Failures
- `NAV_FAIL`:
  - Return to `EXPLORE`

#### Launch Failures
- `LAUNCH_FAIL`:
  - Retry launch in the same state

#### Marker Loss
- `MARKER_LOST`:
  - Return to `EXPLORE`

---

## Communication Architecture

### Topics

| Topic | Type | Description |
|---|---|---|
| `/states` | String | FSM state commands (e.g., `DOCK_3`) |
| `/operation_status` | String | Feedback from subsystems |
| `/aruco_pose` | PoseStamped | Marker detection input |
| `/current_marker` | Int32 | Current marker ID |

---

### Message Protocol (`/operation_status`)

#### Success Messages
- `DOCK_DONE`
- `LAUNCH_DONE`
- `MAP_DONE`

#### Error Messages
- `DOCK_FAIL`
- `LAUNCH_FAIL`
- `NAV_FAIL`
- `MARKER_LOST`
- `TIMEOUT`

---

## Key Design Features

### Dynamic Marker Handling
- No hardcoded stations (A/B)
- Scales to any number of markers

### Centralized Feedback Channel
- All subsystems report to `/operation_status`
- Simplifies debugging and integration

### Fault-Tolerant Execution
- Controlled retry logic for docking
- Graceful fallback on timeout
- No infinite retry loops

### Decoupled Architecture
- FSM = decision-making layer
- Execution handled by separate nodes (Nav2, docking, launcher)

---

## Summary

The FSM provides a robust, scalable, and modular control architecture for autonomous mission execution. By combining dynamic state representation, centralized communication, and fault handling—including retry logic and timeout-based fallback—the system achieves reliable operation in uncertain environments.

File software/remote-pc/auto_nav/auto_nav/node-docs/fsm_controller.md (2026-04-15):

# Finite State Machine (FSM)

## Overview

The mission is orchestrated by the `fsm_controller` node. It publishes
the active mission state on `/states`, listens for execution feedback
on `/operation_status`, and polls the TF tree directly for ArUco
markers (frames `aruco_marker_<id>`) to decide when to break out of
exploration and begin docking. Unlike a hard-coded state set, docking
and exploration are parameterised by the detected marker ID
(e.g. `DOCK_3`, `EXPLORE_1`).

---

## FSM Diagram
fsm-diagram

---

## State Definitions

### EXPLORE / EXPLORE_<id>
Robot runs frontier-based exploration. While in this state the FSM
continuously polls the TF tree for known markers (`aruco_marker_<id>`)
and publishes the matching exploration sub-state:

- `EXPLORE` — no marker targeted yet; pure frontier search.
- `EXPLORE_<id>` — a marker is visible but still further than the
  docking trigger threshold (0.8 m); the exploration node is told to
  head toward it while continuing frontier search.

Completed markers are added to a skip list and never re-detected.

### DOCK_<id>
Triggered when a locked-on marker comes within 0.8 m of `base_link`.
Docking is executed by `docking_node` (three-phase: odom → TF →
LIDAR). Up to 2 dock attempts are allowed per marker.

### STATIC_LAUNCH / DYNAMIC_LAUNCH
Dispatched after `DOCK_DONE` based on the docked marker ID:

- Marker 1 → `STATIC_LAUNCH`
- Marker 2 → `DYNAMIC_LAUNCH`

### END
Mission complete. FSM logs "Mission Complete!" and stops transitioning.

---

## State Transitions

### Normal Operation

- `EXPLORE` → `EXPLORE_<id>` when a marker is spotted beyond 0.8 m
- `EXPLORE*` → `DOCK_<id>` when the target marker is within 0.8 m
- `DOCK_<id>` → `STATIC_LAUNCH` / `DYNAMIC_LAUNCH` on `DOCK_DONE`
- `STATIC_LAUNCH` / `DYNAMIC_LAUNCH` → `EXPLORE` on `LAUNCH_DONE`

---

### Error Handling

Error feedback is received on `/operation_status`:

- `DOCK_FAIL` — retry docking up to 2 attempts total. If the second
  attempt also fails, the marker is added to the completed set (so it
  is skipped in future) and the FSM returns to `EXPLORE`.
- `TIMEOUT` — return to `EXPLORE`, clear target marker, reset dock
  attempt counter.
- `LAUNCH_FAIL` — re-publish the relevant launch state
  (`STATIC_LAUNCH` / `DYNAMIC_LAUNCH`).
- `NAV_FAIL`, `MARKER_LOST` — return to `EXPLORE`.

---

## Communication

### Topics

| Topic | Type | Direction | Description |
|---|---|---|---|
| `/states` | `std_msgs/String` | FSM → nodes | Mission state commands (`EXPLORE`, `EXPLORE_<id>`, `DOCK_<id>`, `STATIC_LAUNCH`, `DYNAMIC_LAUNCH`, `END`) |
| `/operation_status` | `std_msgs/String` | nodes → FSM | Feedback strings (see below) |

### `/operation_status` values

**Success:** `DOCK_DONE`, `LAUNCH_DONE`, `MAP_DONE`

**Errors:** `DOCK_FAIL`, `LAUNCH_FAIL`, `NAV_FAIL`, `MARKER_LOST`,
`TIMEOUT`, `LAUNCH_TIMEOUT`, `LAUNCH_INCOMPLETE`

### Marker discovery

The FSM reads the TF tree directly (it does not subscribe to a
dedicated marker topic). Every 0.5 s it scans for `aruco_marker_<id>`
frames, looks up the transform to `base_link`, and uses the Euclidean
distance to decide between `EXPLORE_<id>` and `DOCK_<id>`.

---

## Key Design Features

- **Dynamic marker handling** — `DOCK_<id>`, `EXPLORE_<id>` scale to
  any marker without hard-coded stations.
- **Target locking** — once a marker is seen beyond the docking
  threshold, the FSM locks onto that ID until completion, ignoring
  other markers.
- **Completed-marker skip list** — a marker that succeeds (or fails
  twice) is added to `completed_markers` and never re-selected.
- **Fault tolerance** — bounded dock retries, `TIMEOUT`-to-explore
  fallback, and graceful mission-end on unrecoverable errors.

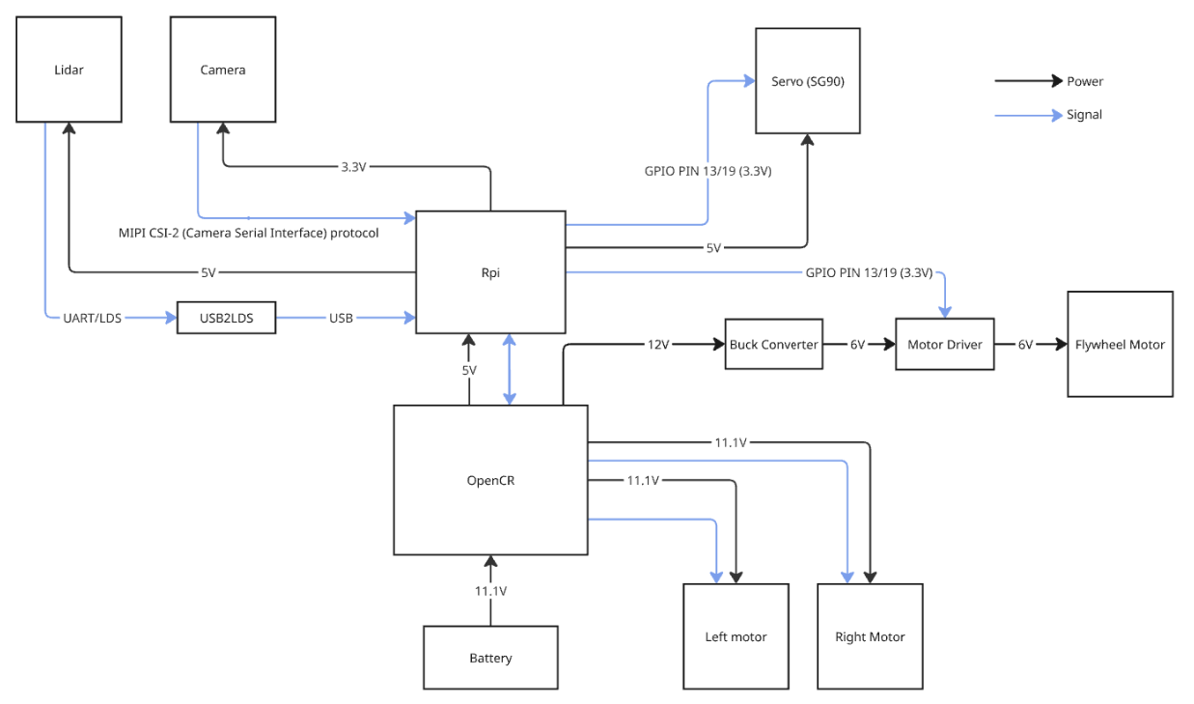
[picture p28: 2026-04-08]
docs/04-subsystem-design/assets/electronics_archi.png

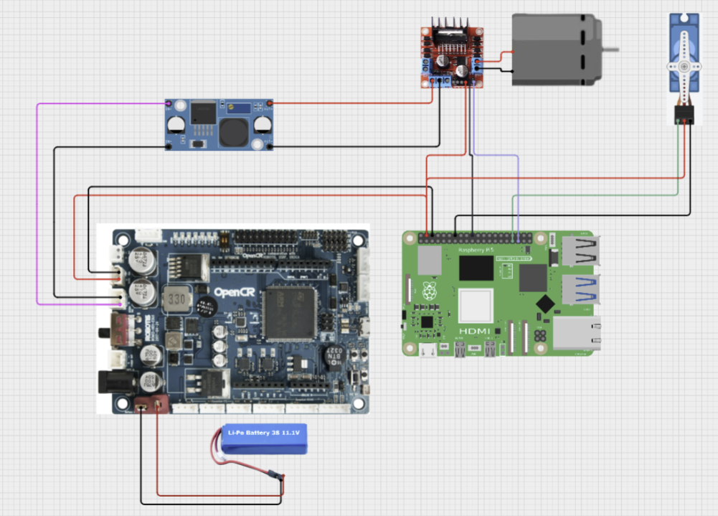
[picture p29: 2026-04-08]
docs/04-subsystem-design/assets/electronic_launcer.png

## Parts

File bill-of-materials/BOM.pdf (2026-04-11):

# Bill of Materials (BOM) – Additional / Purchased Parts

Part | Description | Qty | Unit (SGD) | Total (SGD) | Source
Micro DC-DC buck converter | Buck Converter | 1 | 3.05 | 3.05 | Online
3D-Printing | Launcher components | 3.12 | 5.00/hr | 15.60 | NUS EDIC Lab
130 DC Motor | Flywheel drive motor | 2 | 1.30 | 2.60 | Online
PCB Protoboard 4×6 cm | Solder board for driver | 2 | 1.45 | 2.90 | Online
6 mm OD Aluminium Tube 250 mm | Ramp guides | 6 | 2.61 | 15.66 | Online
USB A to USB C cable | — | 1 | 3.00 | 3.00 | Online
128*64 I2C SSD1306 OLED Display | Launcher Display Module | 1 | 4.38 | 4.38 | Online
6 mm × 6 mm Surface-Mount Momentary Tactile Switch (4-pin) | Push Button for Launcher Control Module | 1 | 0.90 | 0.90 | Online
10 kΩ Single-Turn Adjustable Potentiometer | Adjustable Resistor (Potentiometer) for Launcher controller | 1 | 0.65 | 0.65 | Online
ATmega328P Arduino Nano V3 | Launcher Control Module Microcontroller | 1 | 10.36 | 10.36 | Online
1000 µF 25 V Radial Aluminum Electrolytic Capacitor | Capacitor for Launcher Control Module | 1 | 1.64 | 1.64 | Online
IRLZ44N MOSFET | MOSFET for Launcher motor controller | 1 | 4.52 | 4.52 | Online
Resistor, 100kΩ | Pull-down resistor for launcher controller pushbutton & MOSFET gate | 2 | - | - | NUS EDIC Lab
Diode, 50V 3A | Flyback diode for launcher motor | 1 | - | - | NUS EDIC lab
Total | | | | 65.26

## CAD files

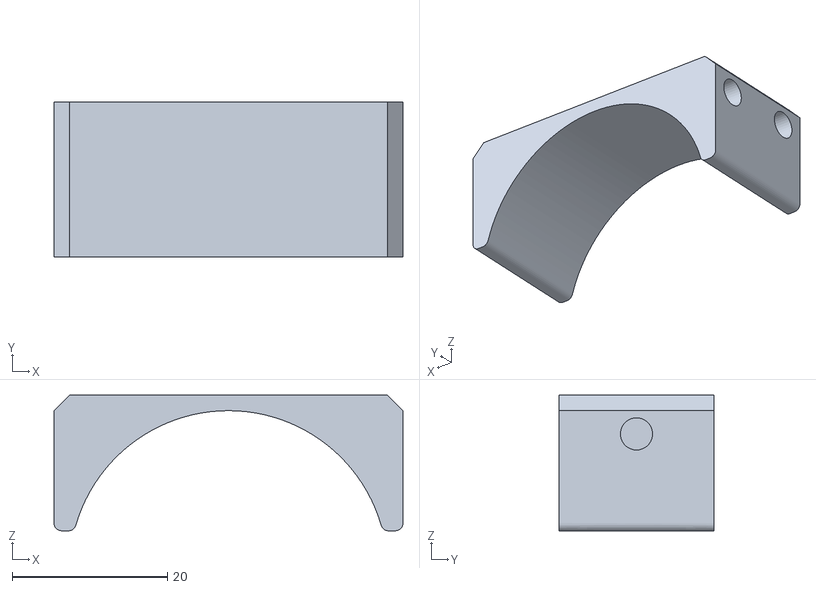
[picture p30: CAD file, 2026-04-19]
hardware/3D print STLs/ball hood.stl
45.0 x 20.0 x 17.5

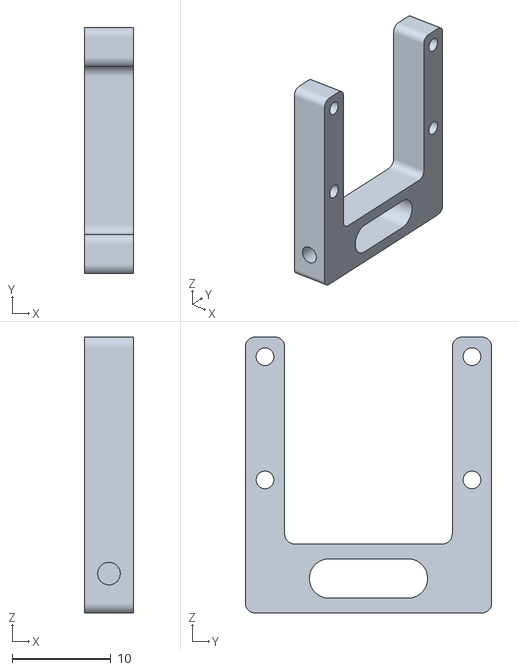
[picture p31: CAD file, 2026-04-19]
hardware/3D print STLs/camera mount.stl
5.00 x 25.0 x 28.0

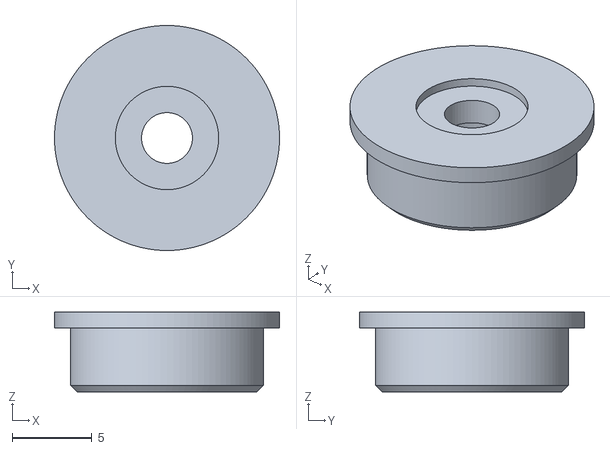
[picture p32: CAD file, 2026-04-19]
hardware/3D print STLs/gear side bearing adapter.stl
14.1 x 14.1 x 5.00

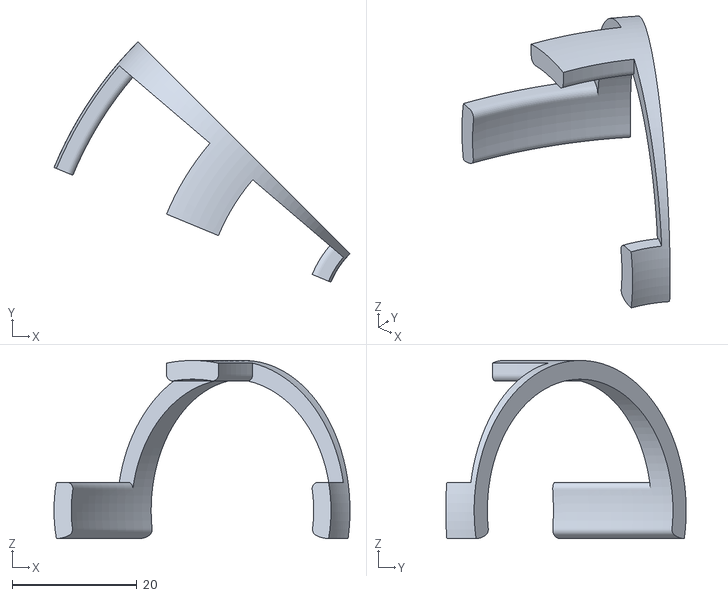
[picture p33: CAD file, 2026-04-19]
hardware/3D print STLs/90 angled ramp (4) x2.stl
47.4 x 38.5 x 28.5

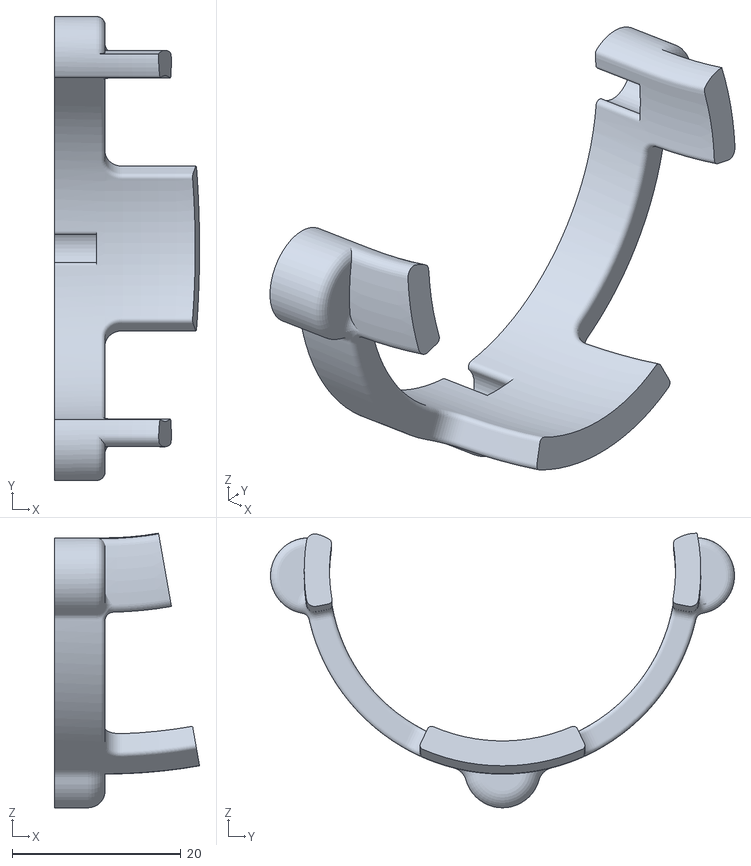
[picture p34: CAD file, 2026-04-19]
hardware/3D print STLs/launcher ramp adapter.stl
17.2 x 55.0 x 32.6

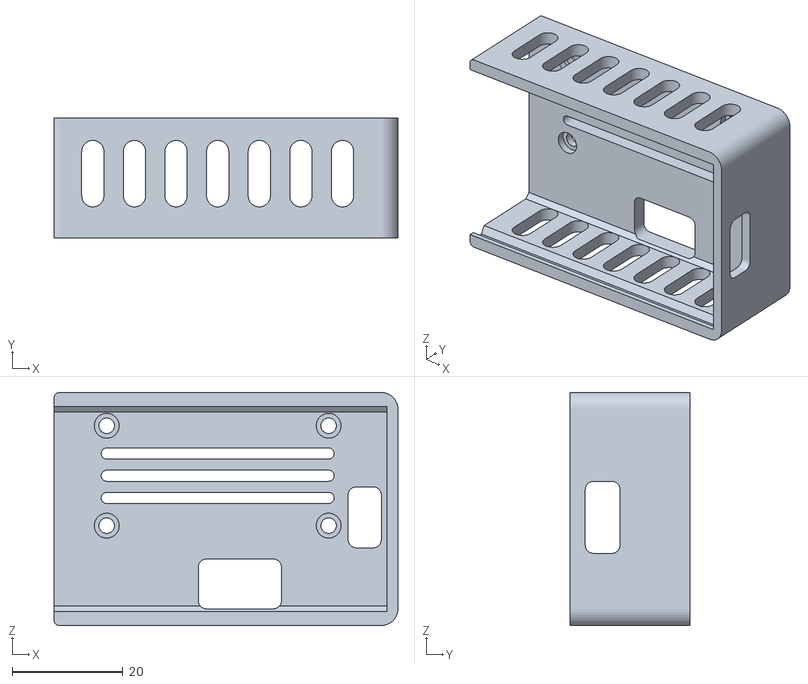
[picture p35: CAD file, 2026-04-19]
hardware/3D print STLs/PCB case.stl
62.0 x 21.6 x 42.0

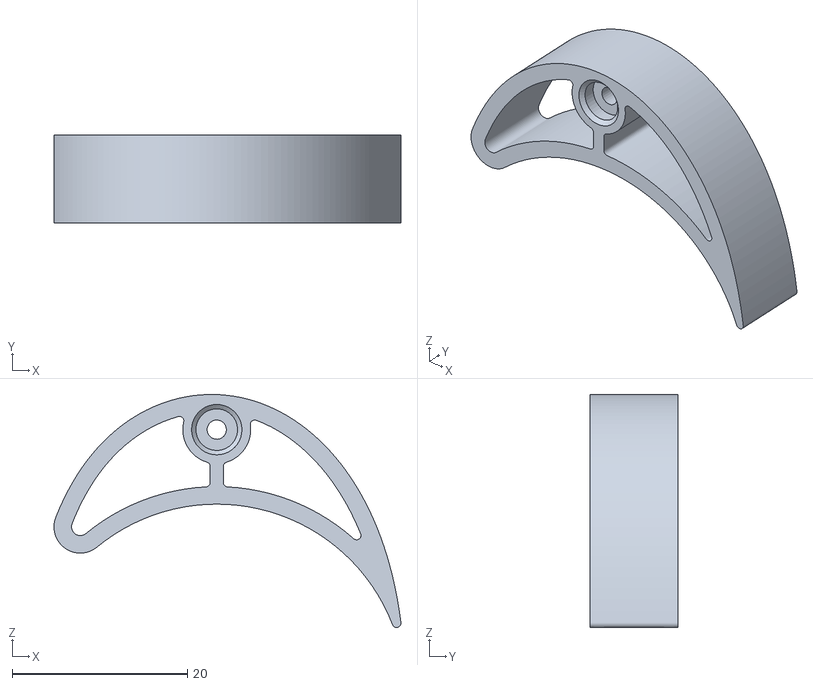
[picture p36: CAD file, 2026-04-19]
hardware/3D print STLs/ball indexer.stl
39.6 x 10.0 x 26.6

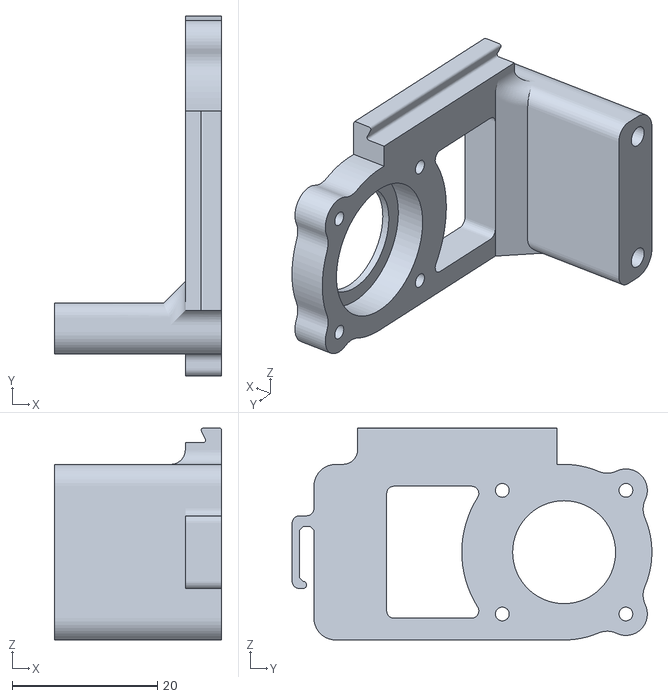
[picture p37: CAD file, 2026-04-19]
hardware/3D print STLs/L-shape housing.stl
23.0 x 49.5 x 29.2

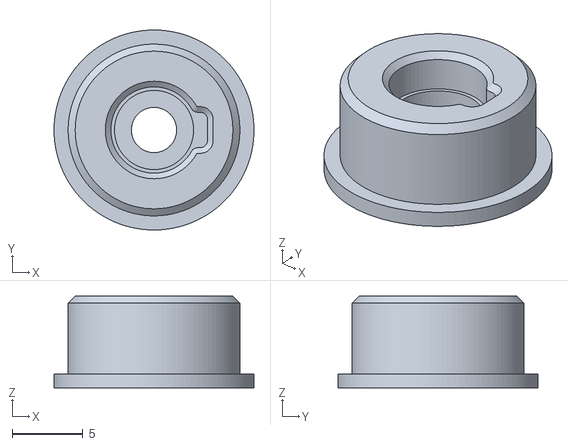
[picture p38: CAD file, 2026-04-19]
hardware/3D print STLs/idle bearing adapter.stl
14.1 x 14.1 x 6.50

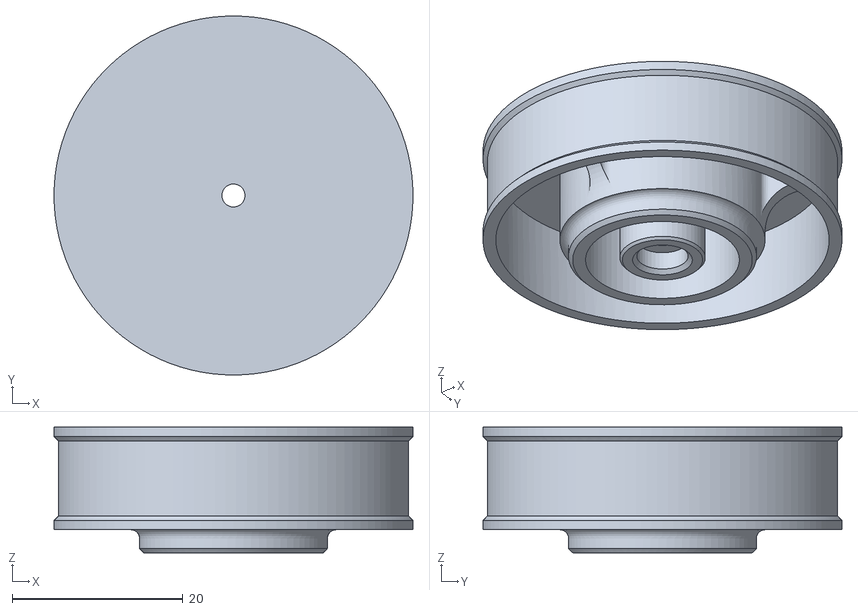
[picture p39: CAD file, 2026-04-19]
hardware/3D print STLs/flywheel.stl
42.0 x 42.0 x 14.7

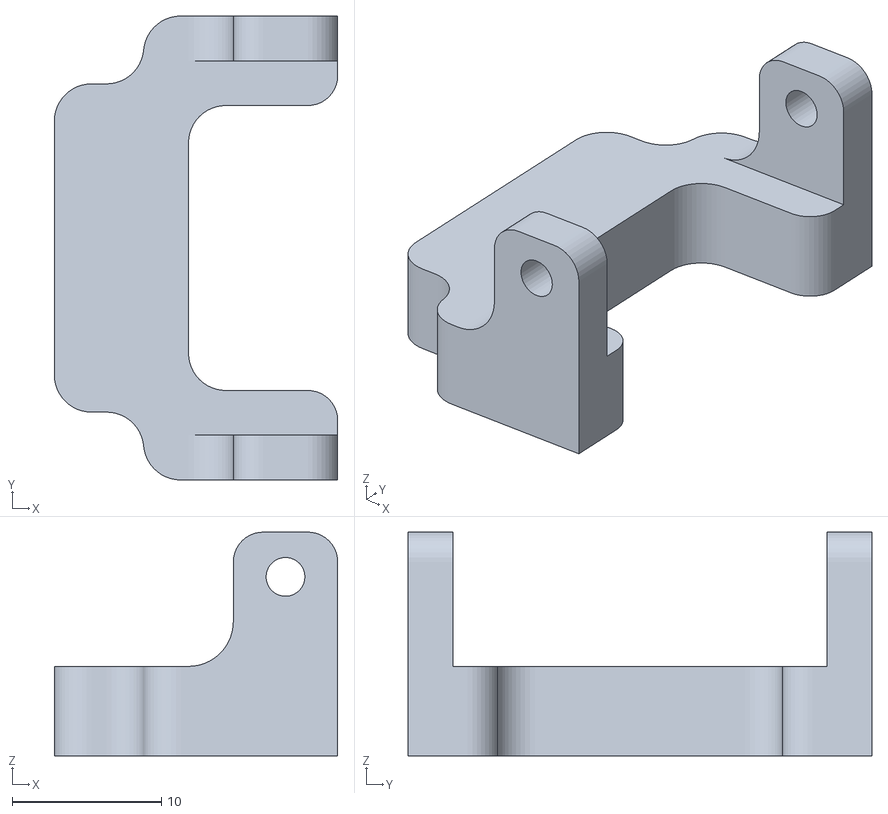
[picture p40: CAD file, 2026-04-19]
hardware/3D print STLs/camera base.stl
19.0 x 31.1 x 15.0

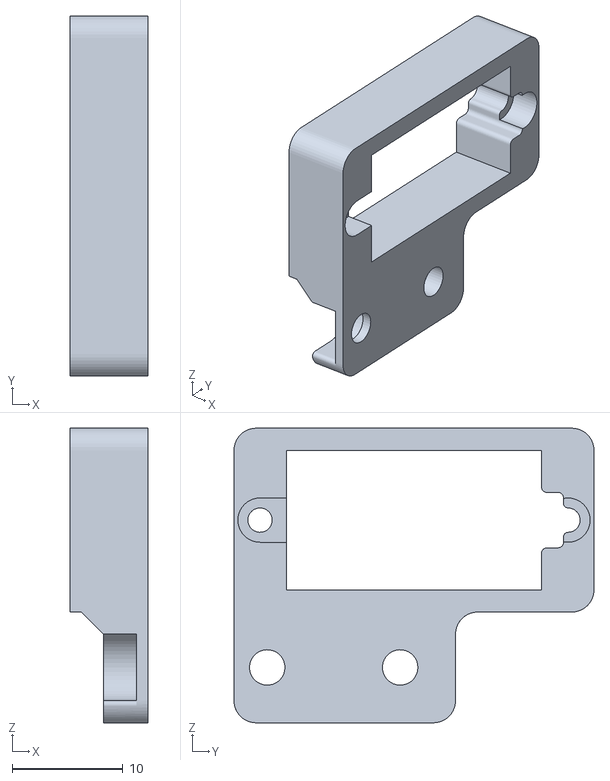
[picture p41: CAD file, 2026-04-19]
hardware/3D print STLs/servo mount.stl
7.00 x 32.5 x 26.6

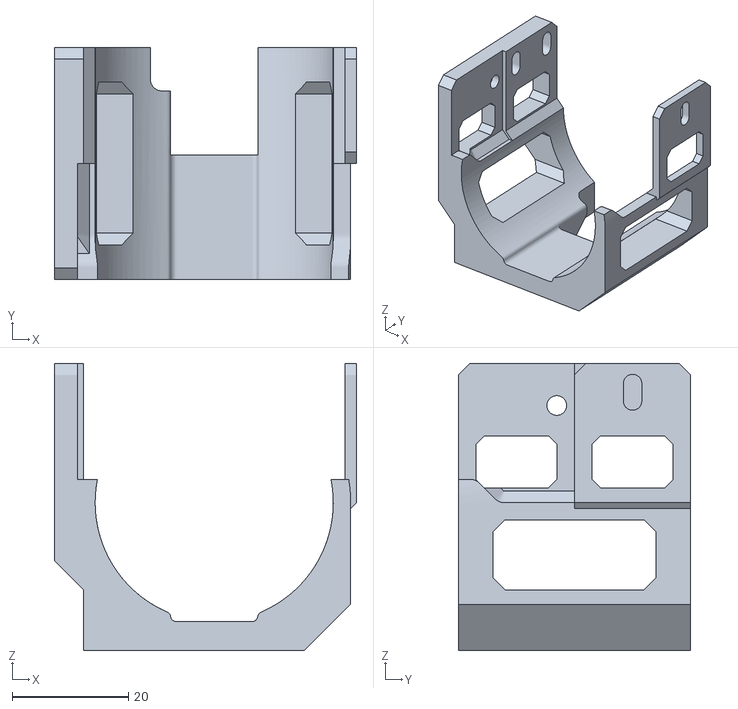
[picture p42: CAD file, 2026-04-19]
hardware/3D print STLs/lancher barrel.stl
52.0 x 40.0 x 49.5

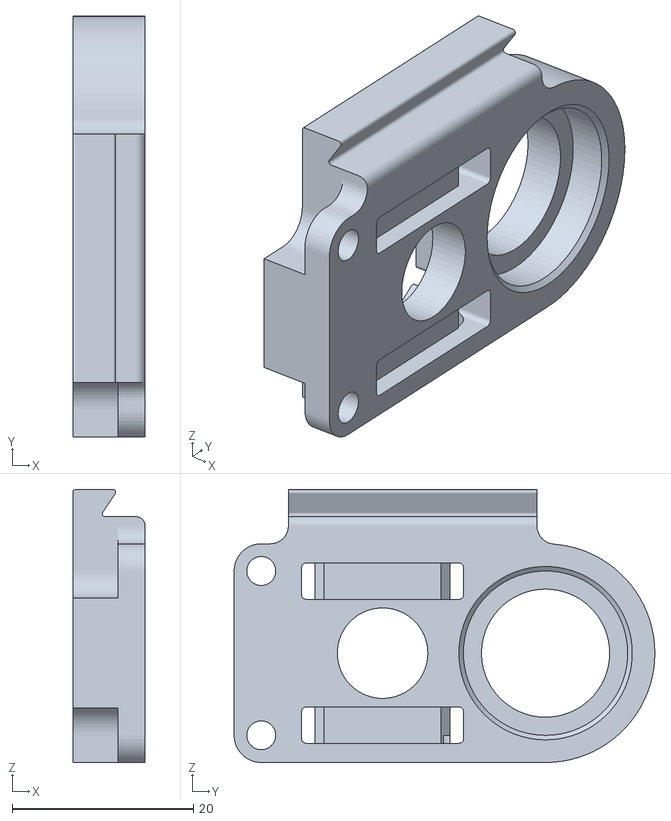
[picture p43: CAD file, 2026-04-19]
hardware/3D print STLs/motor housing.stl
8.00 x 46.5 x 30.2

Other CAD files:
hardware/3D print STLs/motor ziptie adapter.stl
hardware/3D print STLs/PCB case mount x2.stl
hardware/3D print STLs/launcher mount.stl
hardware/3D print STLs/90 angled ramp (1) x2.stl
hardware/3D print STLs/90 angled ramp (2) x2.stl
hardware/3D print STLs/lidar stand.stl
hardware/3D print STLs/terminal bracket.stl

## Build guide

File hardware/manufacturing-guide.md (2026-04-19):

# 3D Printing

All the 3D printed components can be found in the folder `\3D print STLs`.

## Print settings
- If on Bambu/Orca slicer, select standard 0.2mm layer height profile
- Default infill 15%
- Import all components, and auto arrange
- Enable supports (tree), and set to auto
- Select "remove small overhangs" under support settings

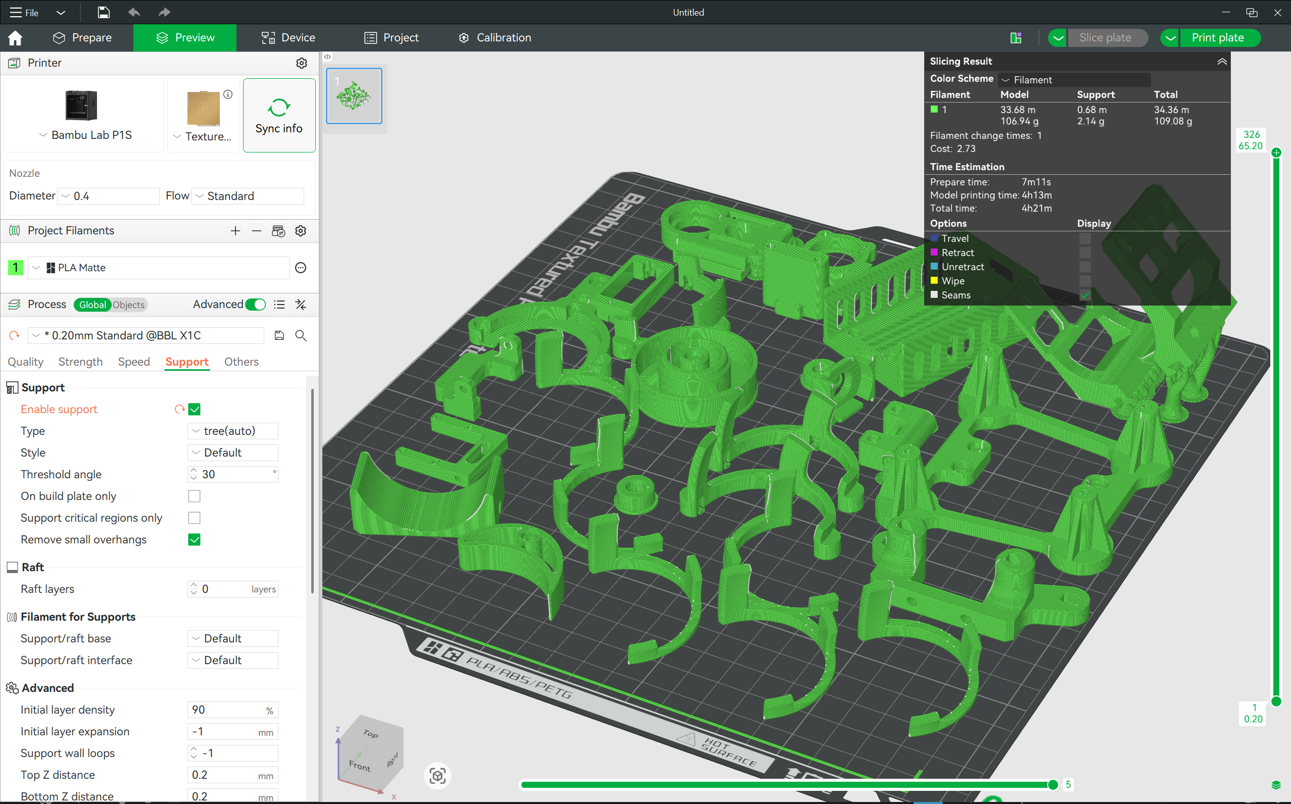
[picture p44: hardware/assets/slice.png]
slice


The print takes just over 4 hours for all 26 components, and only uses 2.14g of support material (<2% of total material)!

---

# Off-the-shelf Components

- 6mm outer diameter, hollow aluminium rods can be purchased from Shopee or physically at ArtFriend (comes in pack of 3).
- Cut aluminium rods to length using a standard small tubing cutter

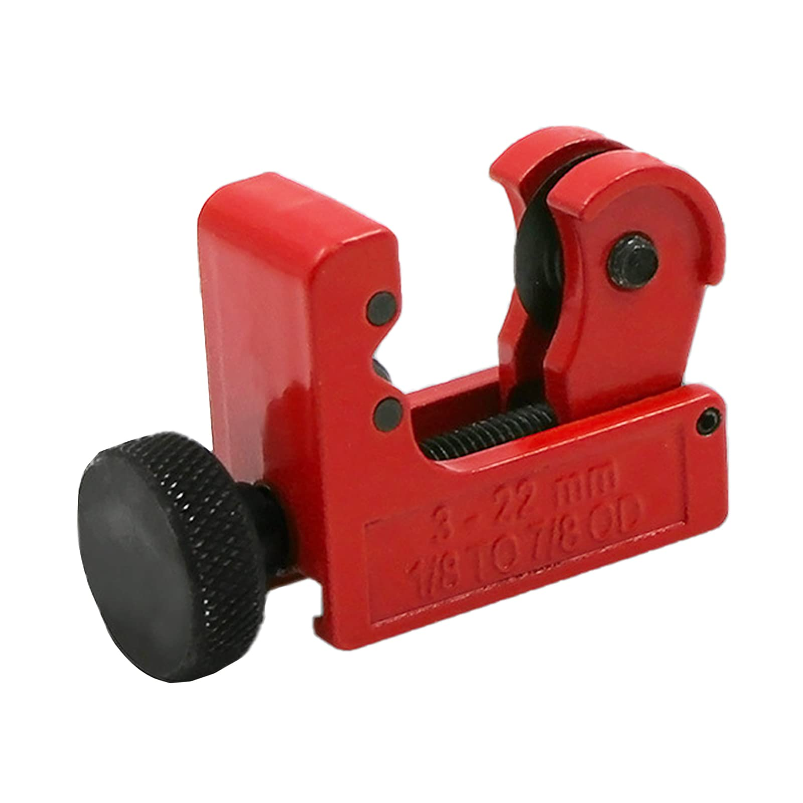
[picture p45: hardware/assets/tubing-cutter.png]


---

# Flywheel rim

The flywheel rim was fabricated from the common thick yellow rubber band.

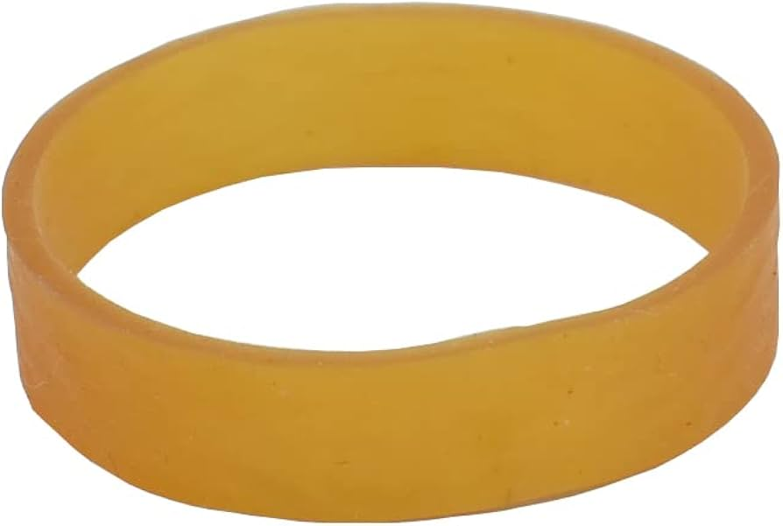
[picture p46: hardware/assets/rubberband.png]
rubberband


If the rubber band is too loose, trim it to length and join it by gluing the 2 ends with a piece of backing material underneath. Simply gluing the 2 ends of the rubber band results in a very unreliable bond. Superglue is also known to cause the rubber band to become brittle over time, hence the backing material is required to allow more contact surface area and load distribution.

The backing material can simply be a piece of plastic cut out from heat shrink tubing.

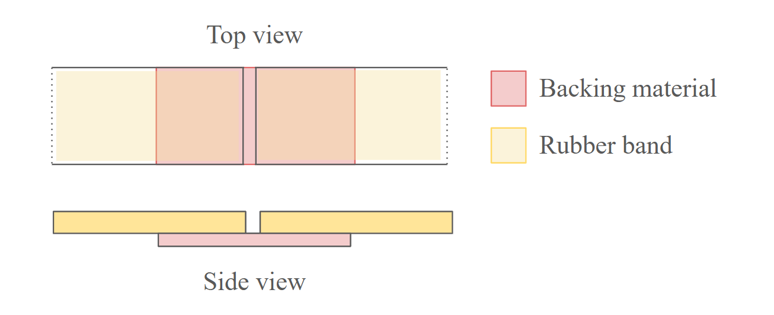
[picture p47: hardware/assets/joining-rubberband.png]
rubberband


# Post-processing

- Assuming parts are printed in PLA, heat-set inserts can be installed at a temperature of 250°
- Friction fit components such as the dovetail joint between flywheel assembly and launcher barrel may require light sanding for proper engagement.

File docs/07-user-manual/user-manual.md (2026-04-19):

# User Manual
**TurtleBot3 | Group 5 | CDE2310 | v1.1.0 | 14 Apr 2026**

---

## Table of Contents

1. [System Specification](#1-system-specification)
2. [Remote PC Setup](#2-remote-pc-setup)
3. [Pre-Mission Procedure](#3-pre-mission-procedure)
4. [Mission Operation](#4-mission-operation)

---

## 1. System Specification

| Field | Detail |
|---|---|
| Model / Platform | TurtleBot3 Burger (Modified – G5) |
| Software Version | v1.1.0 |
| ROS Version | ROS 2 Humble |
| Total Mass | ~1095 g (including launcher assembly) |
| Centre of Gravity (x, y, z) | (−2.28, −8.18, 71.75) mm from robot base centre |
| Battery | LI-PO 11.1V 1800mAH LB-12 19.98Wh 5C |
| Drive Motors | DYNAMIXEL XL430-W250 × 2 |
| LiDAR | LDS-02 (360°, top-mounted) |
| Camera | Raspberry Pi Camera Module V2 (forward-facing) |
| SBC | Raspberry Pi 4 |
| MCU (navigation) | OpenCR 1.0 |
| MCU (launcher) | Arduino Nano |
| Flywheel Motor | 130 DC Motor 6V; driven via L298N (isolated 9V supply) |
| Servo Gate | SG90; position (−75, −18, 130) mm |
| Ramp Guides | 6 mm OD aluminium tubes × 6; 250 mm each |

### Key Software Nodes

| Node | Function |
|---|---|
| `exploration2` | Path planning, obstacle avoidance, recovery behaviours, online SLAM |
| `aruco_detector2` | ArUco marker detection; static vs. dynamic classification |
| `docking` | Three-phase autonomous docking: odom nav to standoff → TF fine approach → LIDAR final approach |
| `fsm_controller` | Top-level state machine; sequences all mission tasks |
| `launcher` | Flywheel speed control and servo gate logic |

---

## 2. Remote PC Setup

> Complete this once before the first mission. Not required to be repeated on exam day.

### 2.1 Install ROS 2 and TurtleBot3 Packages

Follow the official setup instructions [here](https://emanual.robotis.com/docs/en/platform/turtlebot3/quick-start/#pc-setup).

### 2.2 Clone Repository and Link Packages

Clone the repository to your home directory:

```bash
cd ~
git clone git@github.com:eggsacc/CDE2310-Docs.git
```

Then symlink the ROS 2 remote-PC package into your TurtleBot3 workspace:

```bash
ln -s ~/CDE2310-Docs/software/remote-pc/auto_nav ~/turtlebot3_ws/src/auto_nav
```

> The `rpi/launcher_commander` package is deployed separately on the Raspberry Pi and does not need to be linked to the remote PC workspace.

### 2.3 Configure Nav2 Parameters

Locate the Nav2 parameters file for ROS 2 Humble Burger:

```bash
cd ~/turtlebot3_ws/src/turtlebot3/turtlebot3_navigation2/param/humble
nano burger.yaml
```

Copy and replace the entire contents of `burger.yaml` with the configuration file in `config/burger.yaml` in the repository.

Key parameters of note:

| Parameter | Value | Purpose |
|---|---|---|
| `xy_goal_tolerance` | 0.25 | Nav2 goal reached tolerance |
| `inflation_radius` (local) | 0.16 | Tight clearance for maze walls |
| `inflation_radius` (global) | 0.20 | Global path inflation |
| `use_astar` | true | A* global planner enabled |
| `resolution` | 0.01 | High-resolution costmap |
| `robot_radius` | 0.15 | TurtleBot3 Burger footprint |

### 2.4 Build the Workspace

```bash
cd ~/turtlebot3_ws
colcon build
```
---

## 3. Raspberry Pi Setup

> Complete this once before the first mission. Not required to be repeated on exam day.

### 3.1 Copy Package to Raspberry Pi

From the remote PC, copy the `launcher_commander` package to the Raspberry Pi workspace over SSH:

```bash
scp -r ~/CDE2310-Docs/software/rpi/launcher_commander ubuntu@<RPi-IP>:~/turtlebot3_ws/src/
```

> Replace `<RPi-IP>` with the Raspberry Pi's IP address.

### 3.2 Build the Workspace

SSH into the Raspberry Pi and build the workspace:

```bash
ssh ubuntu@<RPi-IP>
cd ~/turtlebot3_ws
colcon build
```
## 4. Arduino Setup

> Complete this once before the first mission. Not required to be repeated on exam day.

### 4.1 Flash Launcher Firmware

Open `software/arduino/launcher_firmware.ino` in the Arduino IDE. Connect the launcher controller board to the remote PC via USB, then upload the sketch.

## 5. Pre-Mission Procedure

Perform these steps within the 25-minute mission window, before declaring start.

| Step | Action |
|---|---|
| 1 | Power on robot via OpenCR switch. |
| 2 | Go through FAT tests. |
| 3 | Load **6 ping pong balls** onto the ramp. |
| 4 | Verify servo gate encapsulates exactly **one ball** in the idle position. |
| 5 | Place the robot at the **start position** in the maze. |
| 6 | Begin **screen recording of RViz** on the remote PC. |
| 7 | On RPi (SSH) — run `rosbu`. Wait until the terminal prints **`Run!`** before proceeding. |
| 8 | On Remote PC — source the workspace, then run `ros2 run auto_nav mainlaunch` on the mission start command. |
| 9 | Confirm RViz shows an **active LiDAR scan**. |

> ⚠️ Once mission start is declared, **no teleoperation or manual intervention is permitted**. All subsequent operation is fully autonomous.

---

## 6. Mission Operation

### 6.1 Mission Flow

| Phase | Description |
|---|---|
| **Explore & Map** | SLAM + frontier search. Targets ≥ 80% map coverage. Uses ≤ 4 ArUco landmark markers. |
| **Dock** | On detecting a marker within range, the docking node executes three phases: (1) odom dead-reckoning to a 45 cm standoff, (2) TF fine approach with EMA filtering to 40 cm, (3) LIDAR final approach at 1 cm/s to 20 cm. Includes 360° recovery spin if marker is lost. Up to 2 retries before skipping. |
| **Station A** | Detects static ArUco (ID 1). Dispenses 3 balls in timed sequence. |
| **Station B** | Detects moving ArUco (ID 2). Tracks receptacle position. Dispenses 3 balls onto moving target. |
| **Recovery** | Nav2 auto re-plans on any navigation failure. No human intervention required. |

### 6.2 Stopping and Re-attempting

To restart the mission within the time window:

1. Power off the robot or interrupt the running nodes with `Ctrl-C`
2. Return the robot to the start position
3. Reload ping pong balls onto the ramp if needed
4. Repeat steps 7–9 from [Section 5](#5-pre-mission-procedure)
5. Inform the TA of any major changes made between attempts

### 6.3 White Flag Procedure (Minute 14)

If the robot has not reached a delivery station by the **14-minute mark**, the team may invoke the white flag rule to score partial points:

1. Interrupt the current run (`Ctrl-C`)
2. Navigate the robot manually to the vicinity of Station A or B
3. Re-run: `ros2 run auto_nav mainlaunch`
4. Inform the TA that the white flag is being invoked

---

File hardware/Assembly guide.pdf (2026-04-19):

# Assembly guide

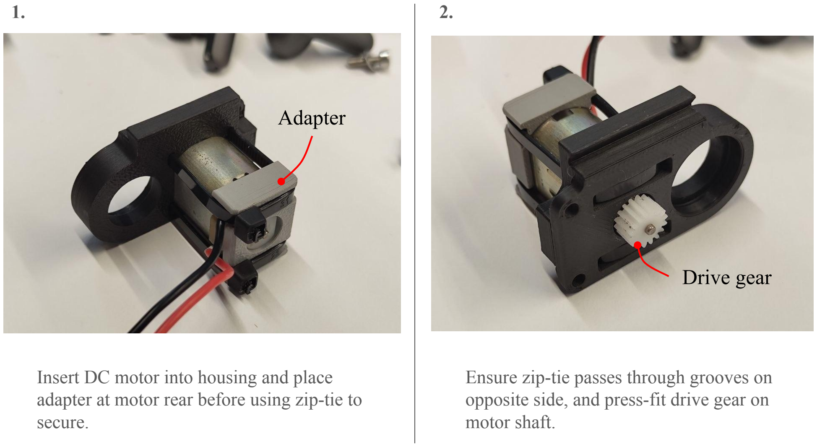
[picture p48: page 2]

Insert DC motor into housing and place adapter at motor rear before using zip-tie to secure.

Ensure zip-tie passes through grooves on opposite side, and press-fit drive gear on motor shaft.

Adapter

Drive gear

1. 2.

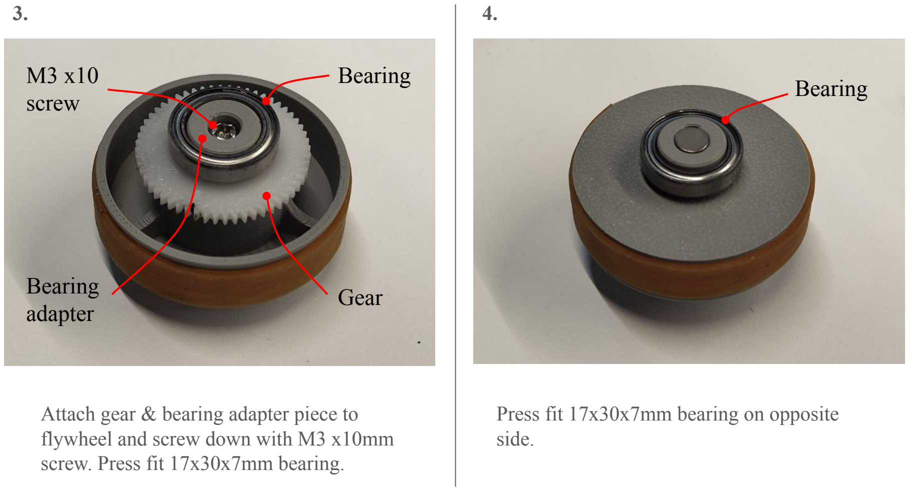
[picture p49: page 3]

3. 4.

Attach gear & bearing adapter piece to flywheel and screw down with M3 x10mm screw. Press fit 17x30x7mm bearing.

Press fit 17x30x7mm bearing on opposite side.

Bearing

Gear

M3 x10
screw

Bearing

Bearing
adapter

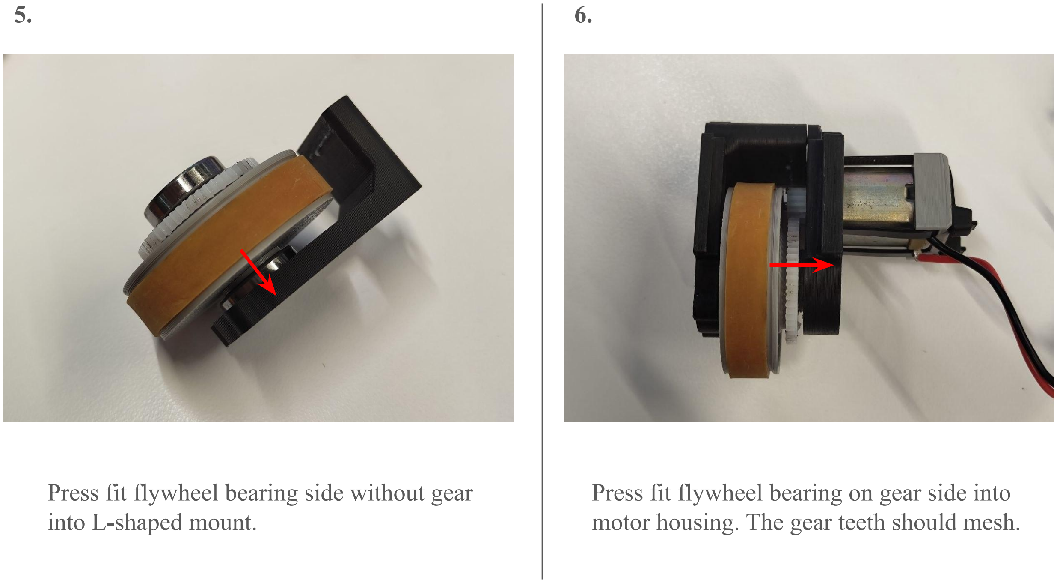
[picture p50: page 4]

5. 6.

Press fit flywheel bearing side without gear into L-shaped mount.

Press fit flywheel bearing on gear side into motor housing. The gear teeth should mesh.

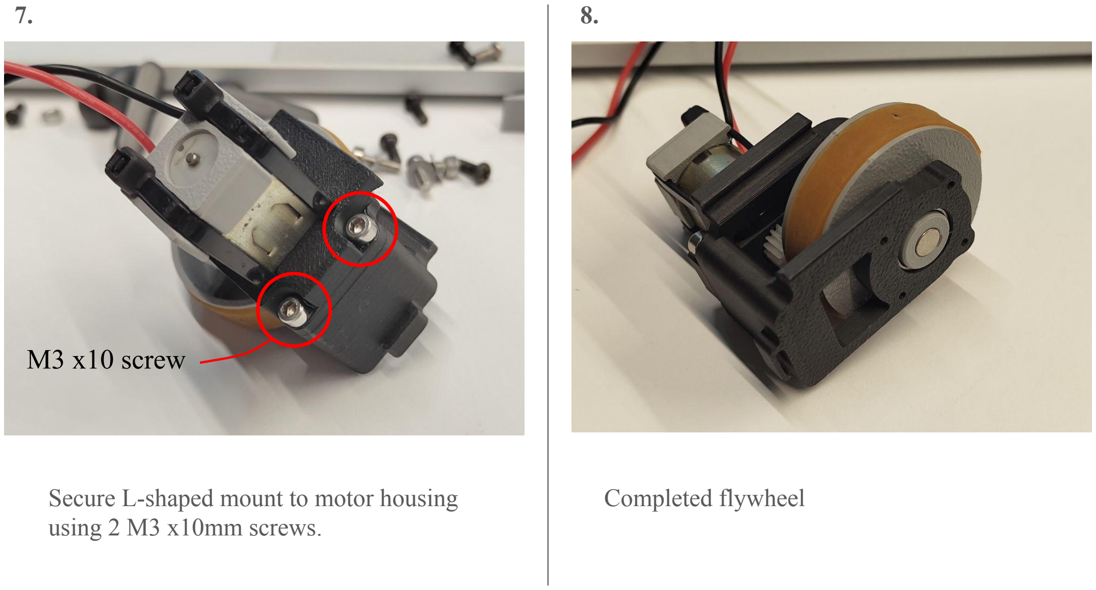
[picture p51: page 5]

7. 8.

Secure L-shaped mount to motor housing using 2 M3 x10mm screws.

Completed flywheel

M3 x10 screw

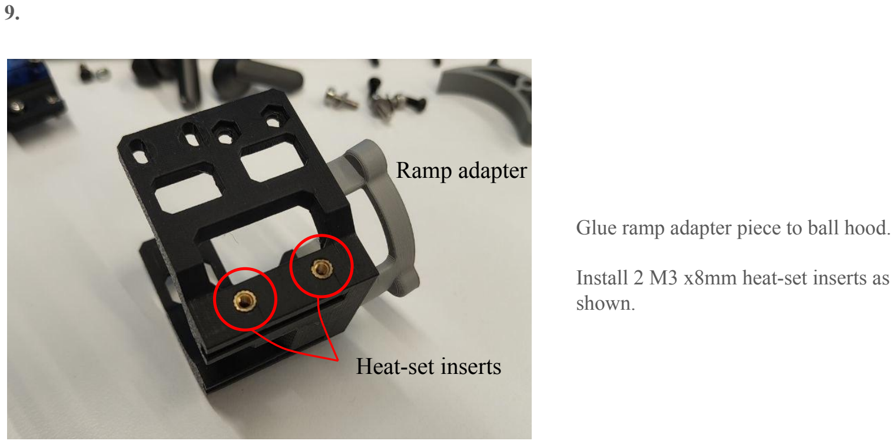
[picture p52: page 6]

9.

Glue ramp adapter piece to ball hood.

Install 2 M3 x8mm heat-set inserts as shown.

Ramp adapter

Heat-set inserts

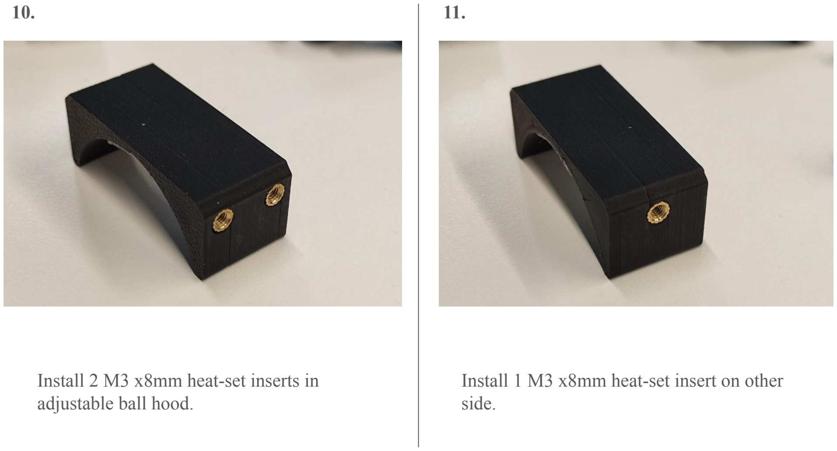
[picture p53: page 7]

10. 11.

Install 2 M3 x8mm heat-set inserts in adjustable ball hood.

Install 1 M3 x8mm heat-set insert on other side.

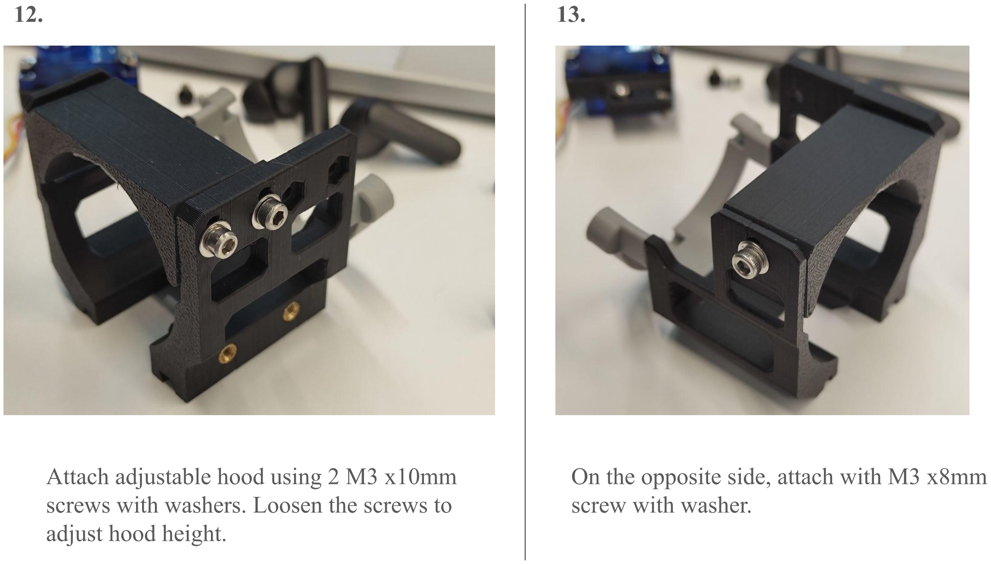
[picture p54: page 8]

12. 13.

Attach adjustable hood using 2 M3 x10mm screws with washers. Loosen the screws to adjust hood height.

On the opposite side, attach with M3 x8mm screw with washer.

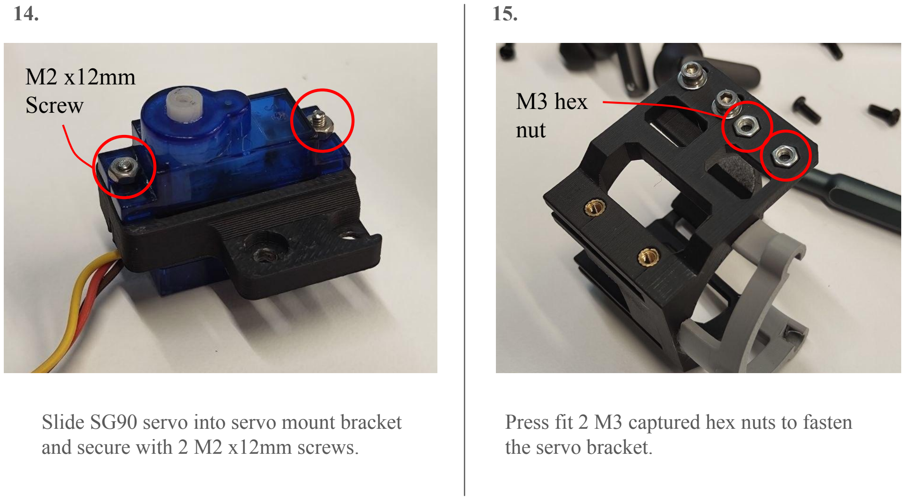
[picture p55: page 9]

14. 15.

Slide SG90 servo into servo mount bracket and secure with 2 M2 x12mm screws.

Press fit 2 M3 captured hex nuts to fasten the servo bracket.

M2 x12mm
Screw | M3 hex
| nut

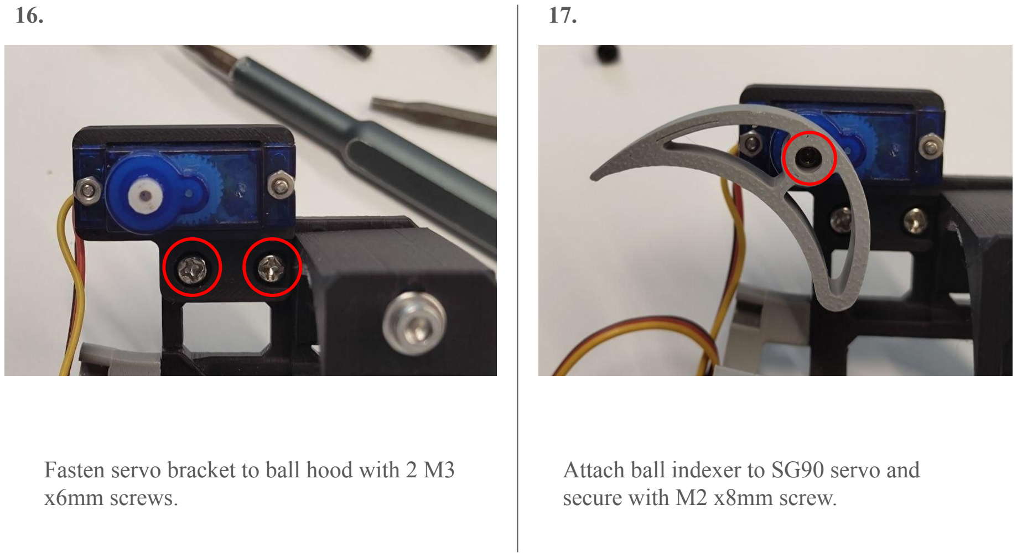
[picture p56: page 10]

16. 17.

Fasten servo bracket to ball hood with 2 M3 x6mm screws.

Attach ball indexer to SG90 servo and secure with M2 x8mm screw.

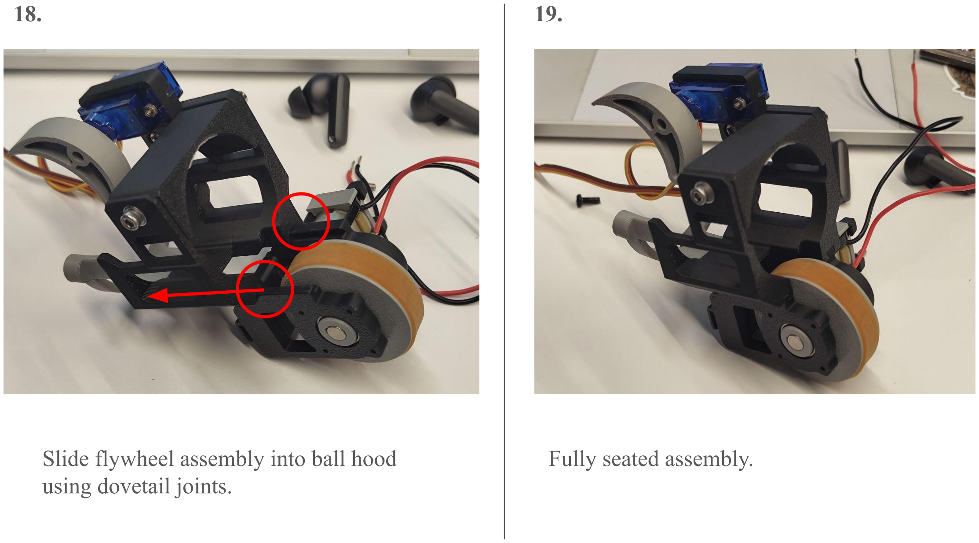
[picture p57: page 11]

18. 19.

Slide flywheel assembly into ball hood using dovetail joints.

Fully seated assembly.

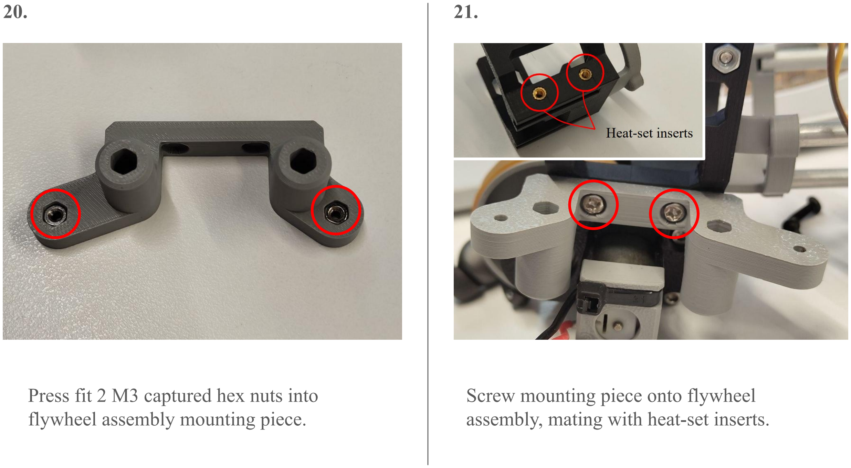
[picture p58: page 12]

20. 21.

Press fit 2 M3 captured hex nuts into flywheel assembly mounting piece.

Screw mounting piece onto flywheel assembly, mating with heat-set inserts.

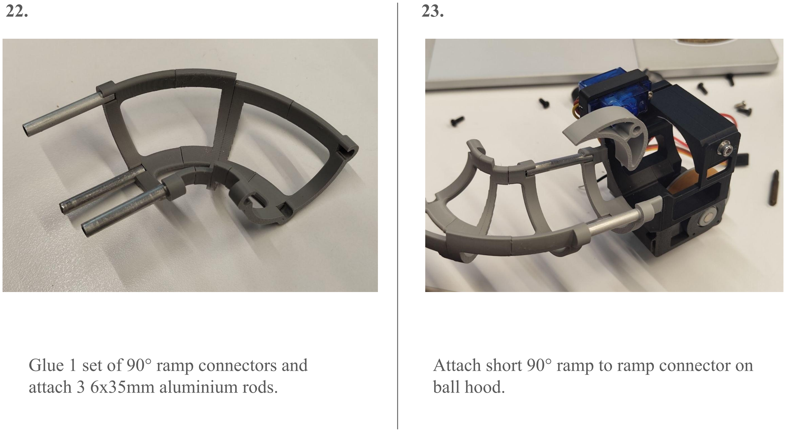
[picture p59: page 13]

22. 23.

Glue 1 set of 90° ramp connectors and attach 3 6x35mm aluminium rods.

Attach short 90° ramp to ramp connector on ball hood.

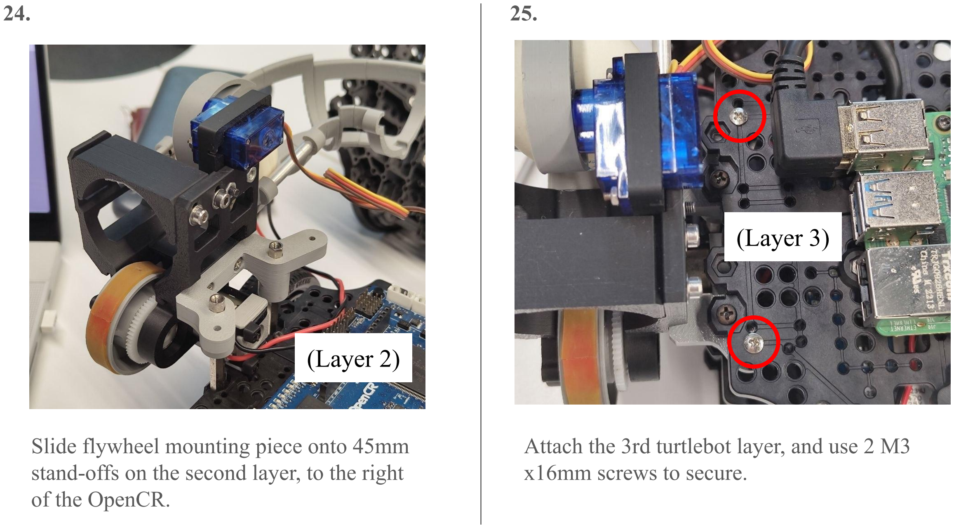
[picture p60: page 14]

24. 25.

Slide flywheel mounting piece onto 45mm stand-offs on the second layer, to the right of the OpenCR.

Attach the 3rd turtlebot layer, and use 2 M3 x16mm screws to secure.

(Layer 3)

(Layer 2)

26.

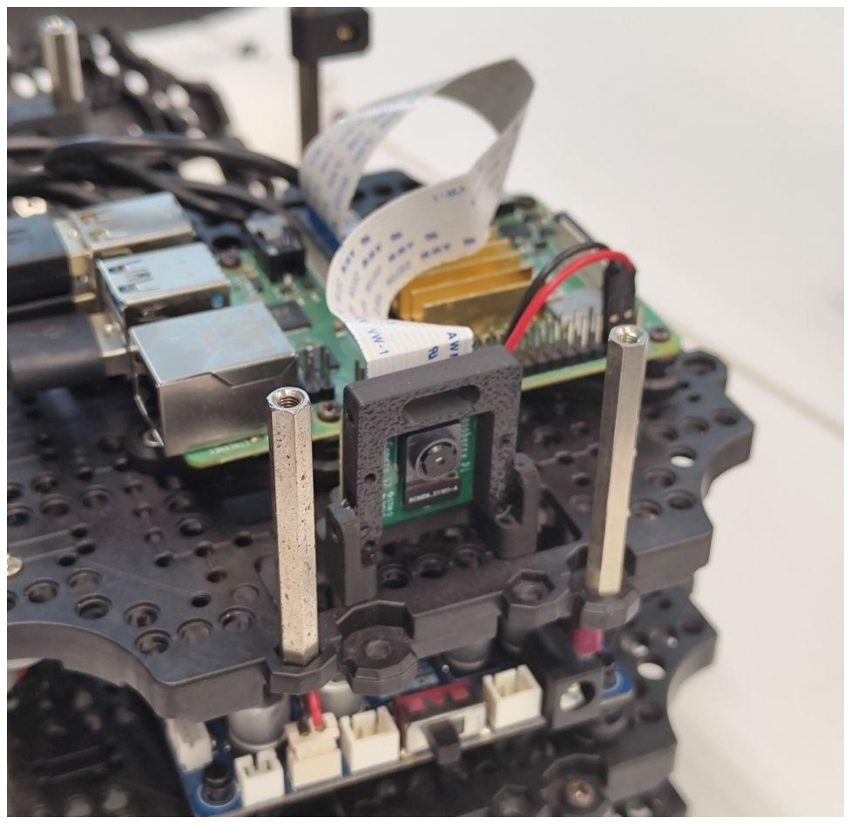
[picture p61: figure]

Screw in the Raspberry Pi camera V2 mount using 2 M3 x12mm screws from the bottom of the plate.

Connect the ribbon cable to the Raspberry Pi.

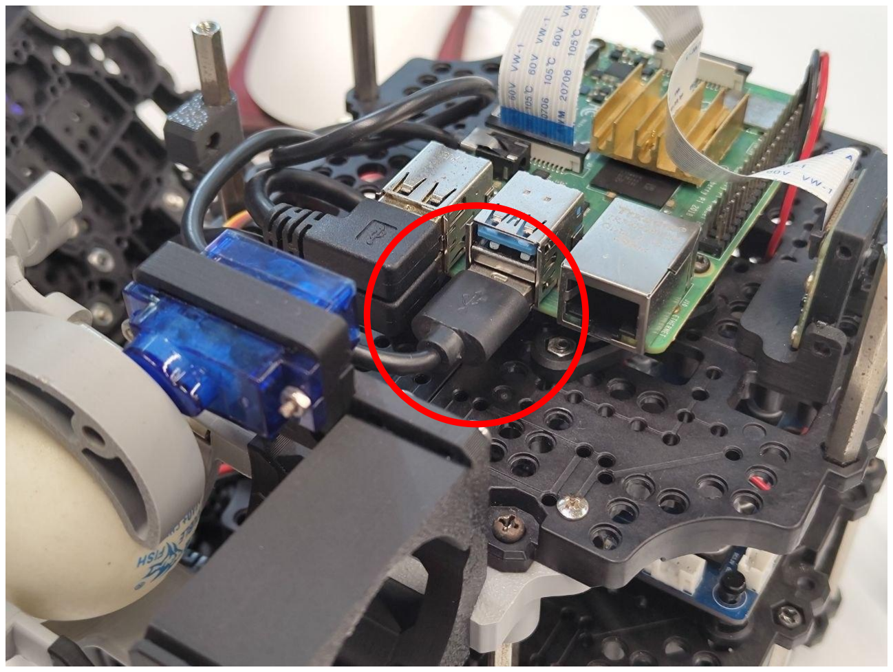
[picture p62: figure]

Plug in USB-C cable for launcher controller module to Raspberry Pi.

27.

28.

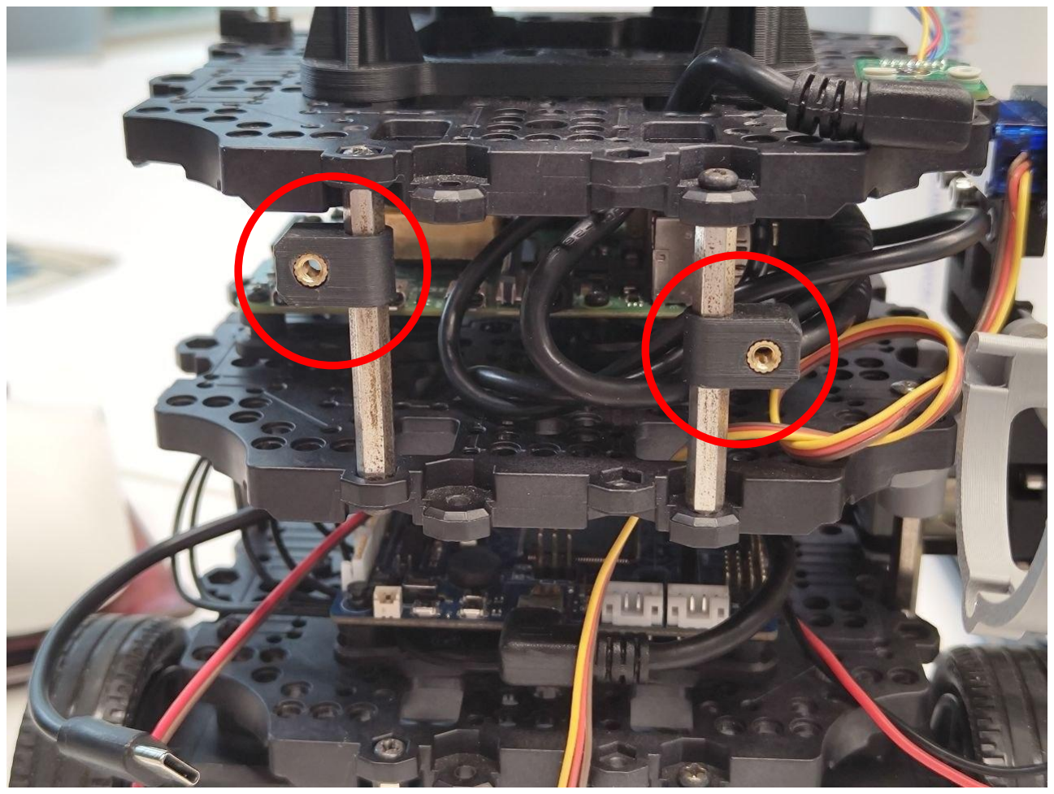
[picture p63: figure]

Install heat-set insert for ramp mounting pieces.

Slide in mounting points for ramp on hex stand-offs on the 3rd layer

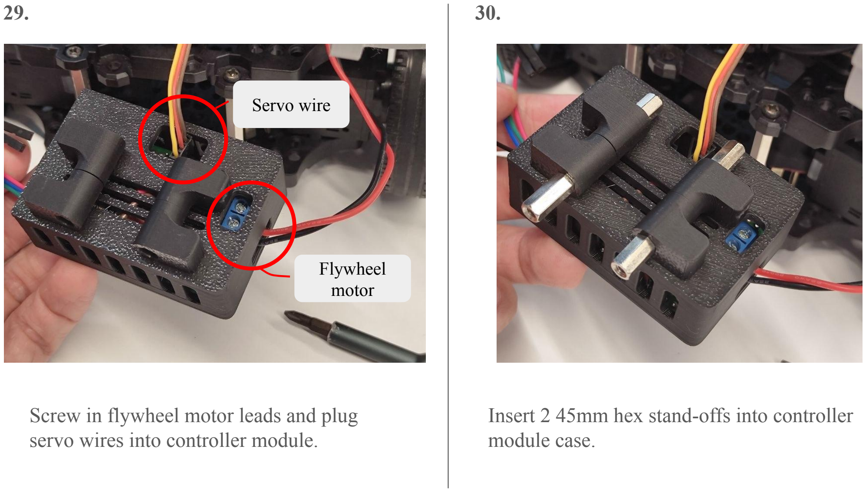
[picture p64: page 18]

29. 30.

Screw in flywheel motor leads and plug servo wires into controller module.

Insert 2 45mm hex stand-offs into controller module case.

Servo wire

Flywheel
motor

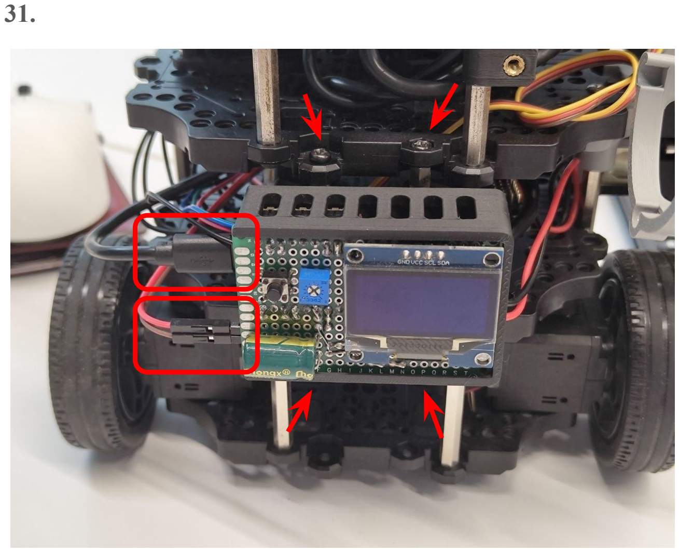
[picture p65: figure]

Install hex stand-offs between layers 2 and 3 with 4x Turtlebot M3 Black screws.

Plug USB-C cable into controller & voltage supply from buck converter.

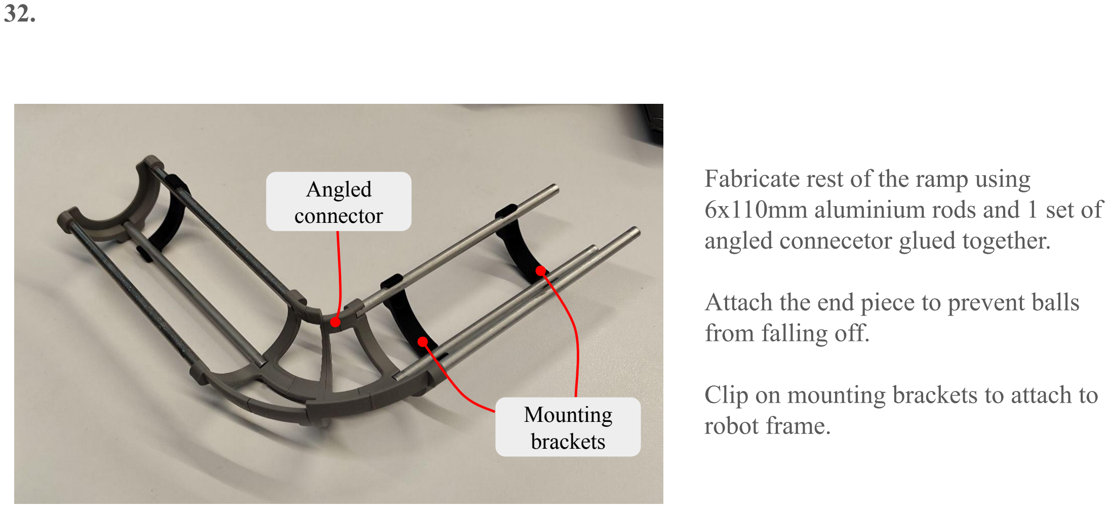
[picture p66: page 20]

32.

Fabricate rest of the ramp using 6x110mm aluminium rods and 1 set of angled connecetor glued together.

Attach the end piece to prevent balls from falling off.

Clip on mounting brackets to attach to robot frame.

Angled
connector

Mounting
brackets

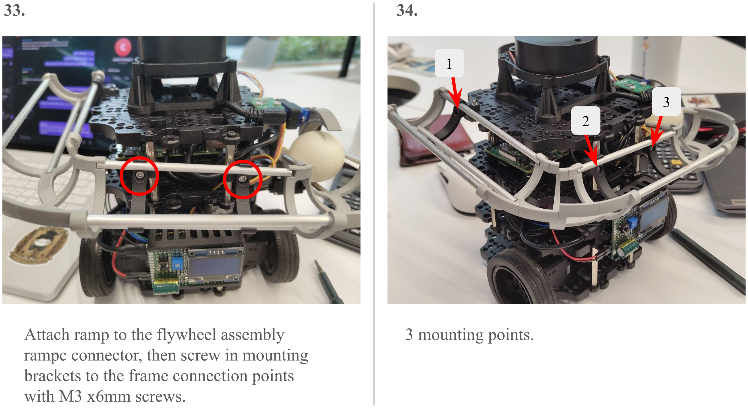
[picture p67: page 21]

33. 34.

Attach ramp to the flywheel assembly rampc connector, then screw in mounting brackets to the frame connection points with M3 x6mm screws.

3 mounting points.

1

2

3

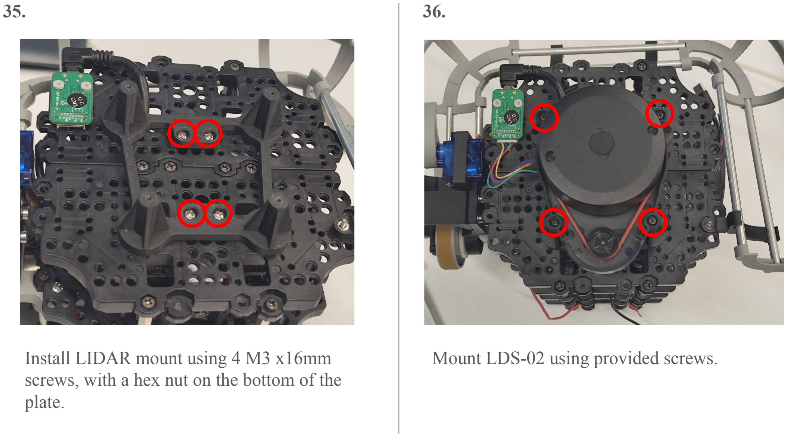
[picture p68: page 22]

35. 36.

Install LIDAR mount using 4 M3 x16mm screws, with a hex nut on the bottom of the plate.

Mount LDS-02 using provided screws.

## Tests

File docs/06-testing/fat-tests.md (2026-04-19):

# Factory Acceptance Tests (FAT)

**Version:** 1.0.0
**Last updated:** 2026-04-19
**Status:** Released

---

## 1. Purpose

The FAT procedure validates every subsystem — mechanical, electrical, perception,
and software — before the mission clock starts. All checks are part of the
25-minute mission window and must pass before launching the full stack.

Two FAT ROS 2 nodes are provided in the `auto_nav` package to automate the
launcher and perception checks:

| File | Subsystem under test | What it does |
|---|---|---|
| `fat_aruco.py` | Perception (camera + ArUco) | Runs the ArUco detection pipeline with verbose logging and factory camera intrinsics. |
| `fat_launch.py` | Launcher (flywheel + feeder) | Runs one full static launch sequence (`SPIN` → 3 × `FIRE` → `STOP`) and reports `FAT PASSED` on success. |

Both scripts are run one at a time on the bench; neither publishes `/states`
nor interacts with the FSM.

---

## 2. Prerequisites

- ROS 2 Humble installed on the remote PC.
- The `auto_nav` package built in the workspace:
  ```bash
  cd ~/turtlebot3_ws
  colcon build --packages-select auto_nav
  source install/setup.bash
  ```
- For the ArUco test: the Raspberry Pi camera node running and
  publishing `/camera/image_raw/compressed`, and the
  `camera_optical_frame` TF available.
- For the launcher test: the RPi serial bridge node running and
  subscribed to `/arduino_cmd`, with the Arduino powered and connected
  over USB.

---

## 3. Test Procedures

### 3.1 Hardware Inspection (H1 – H5, H8, H9)

These are hands-on checks performed before powering on or running any software.

| Step | Action | What to look for |
|---|---|---|
| 1 | Measure main battery voltage with a multimeter or the OpenCR voltage readout. | Voltage ≥ 10.8 V. Do not proceed if below threshold. |
| 2 | Inspect all structural plates, standoffs, and screws on the chassis and launcher assembly. | Every fastener is tight; no plates shift when lightly pressed. |
| 3 | Visually inspect all cabling — USB, power, servo leads, LiPo balance lead. | No cables protrude beyond the chassis footprint or risk snagging on walls. |
| 4 | Power on the robot via the OpenCR switch. Manually rotate both wheels by hand (power off the DYNAMIXELs first if needed). | Wheels spin freely with no binding, grinding, or resistance. |
| 5 | Observe the LDS-02 LiDAR after power-on. | LiDAR spins smoothly at a constant speed with no stuttering or scraping. |
| 6 | Load 6 ping pong balls onto the ramp and let them roll to the servo gate. | Balls roll smoothly down the full length of the ramp without jamming. |
| 7 | Observe the servo gate in its idle (unpowered) position. | The gate holds exactly 1 ping pong ball in the feed position. |

**Pass:** All seven steps show expected behaviour.
**Fail:** Any binding, loose fastener, low voltage, cable snag, or feed jam must be resolved before continuing.

---

### 3.2 ArUco Perception Test (H7)

Validates the camera pipeline and ArUco marker detection using `fat_aruco.py`.

#### Physical setup

1. Power on the robot and ensure the RPi camera node is running.
2. Place a printed `DICT_4X4_50` marker (side length matching `marker_size`, default 0.05 m) approximately 0.5 m in front of the camera under maze lighting conditions.

#### Run the FAT node

**Terminal 1 — RPi (SSH):**
```bash
rosbu
```
Wait until `rosbu` prints `Run!`.

**Terminal 2 — Remote PC:**
```bash
source ~/turtlebot3_ws/install/setup.bash
ros2 run auto_nav fat_aruco --ros-args -p marker_size:=0.05 -p benchmark:=true
```

**Terminal 3 — Remote PC (optional, TF verification):**
```bash
ros2 run tf2_ros tf2_echo camera_optical_frame aruco_marker_1
```

#### ROS 2 parameters

| Parameter | Default | Purpose |
|---|---|---|
| `frequency` | 20 Hz | Detection timer rate. |
| `marker_size` | 0.05 m | Must match the printed marker side length. |
| `verbose` | `False` | Logs "no marker found" / "solvePnP failed" diagnostics. |
| `benchmark` | `False` | Logs per-frame detection and solvePnP timings in ms. |

#### Pass criteria

- An `INFO` log line appears for each detection:
  ```
  Marker ID:1 found, x:0.05, y:-0.02, z:0.53
  ```
- `tf2_echo camera_optical_frame aruco_marker_<id>` returns a translation Z
  that matches the measured camera-to-marker distance to within ~5 cm at 0.5 m.
- If `benchmark:=true`, detection + PnP times are consistently below ~20 ms per frame.

#### Fail indicators

| Symptom | Likely cause |
|---|---|
| `Failed to decode image` warnings | Camera driver not producing valid compressed frames. Check `ros2 topic hz /camera/image_raw/compressed`. |
| No log lines at all with marker in view | Dictionary mismatch (verify `DICT_4X4_50`, not `DICT_6X6_250`) or marker is smaller than `marker_size`. |
| `Marker ID:X found, solvePnP failed.` | Intrinsics badly wrong or marker off-axis beyond ±45°. |

---

### 3.3 Launcher Test (H6)

Validates the flywheel, servo gate, and Arduino serial bridge using `fat_launch.py`.

#### Physical setup

1. Load 6 ping pong balls onto the ramp.
2. Confirm the servo gate holds 1 ball in idle position (checked in 3.1 step 7).
3. Ensure the Arduino Nano is powered and connected to the RPi via USB.
4. Point the launcher muzzle into a safe catch area.

#### Run the FAT node

**Terminal 1 — RPi (SSH):**
```bash
rosbu
```
Wait until `rosbu` prints `Run!`.

**Terminal 2 — Remote PC:**
```bash
source ~/turtlebot3_ws/install/setup.bash
ros2 run auto_nav fat_launch
```

**Terminal 3 — Remote PC (optional, monitor commands):**
```bash
ros2 topic echo /arduino_cmd
```

**Terminal 4 — Remote PC (optional, monitor Arduino replies):**
```bash
ros2 topic echo /arduino_response
```

#### Expected sequence

The node executes one automated cycle:

| Time | Command | Physical behaviour |
|---|---|---|
| T+0.0 s | `SPIN` | Flywheel spins up within ~0.5 s. |
| T+0.5 s | `FIRE` (shot 1/3) | Servo gate releases 1 ball; ball exits muzzle. |
| T+6.0 s | `FIRE` (shot 2/3) | Second ball launched. |
| T+11.5 s | `FIRE` (shot 3/3) | Third ball launched. |
| T+14.5 s | `STOP` | Flywheel spins down to rest. |

#### Pass criteria

- `Bridge connected. Starting static launch.` appears within a few seconds.
- Log shows the full sequence:
  ```
  → Arduino: SPIN
  → Arduino: FIRE    (shot 1/3)
  → Arduino: FIRE    (shot 2/3)
  → Arduino: FIRE    (shot 3/3)
  → Arduino: STOP
  === FAT PASSED — launcher OK ===
  ```
- Physically: flywheel spins up on `SPIN`, exactly 3 balls exit the muzzle, flywheel stops after `STOP`.

#### Fail indicators

| Symptom | Likely cause |
|---|---|
| `No subscriber yet...` loops forever | RPi bridge node not running or subscribed on a different topic name. |
| Commands published but no physical motion | Arduino serial link faulty — test the bridge independently. |
| Fewer than 3 balls fed | Servo/feeder mechanical issue. Only increase the 5.5 s cooldown if the flywheel is visibly not re-spinning in time. |

---

### 3.4 Software & Communication Checks (S1 – S4)

These checks verify end-to-end connectivity before launching the mission.

| Step | Action | Pass criteria |
|---|---|---|
| 1 | From the Remote PC, SSH into the RPi: `ssh ubuntu@<RPI_IP>` | Shell prompt appears without connection errors. |
| 2 | On the RPi run `rosbu`. On the Remote PC source the workspace and run: `ros2 run auto_nav mainlaunch`. Open RViz. | LiDAR scan data is received and plotted on the active RViz map. |
| 3 | Review all terminal windows used during tests 3.1 – 3.3. | No error-level logs or unexpected warnings appeared during hardware testing. |
| 4 | Press Ctrl-C in every terminal running a ROS 2 node. | All nodes terminate cleanly without zombie processes (`ros2 node list` returns empty). |

---

## 4. FAT Checklist

Complete all items before the mission run. Mark each item **P** (pass) or **F** (fail).

### Hardware

| # | Check Item | Test ref. | P / F |
|---|---|---|---|
| H1 | Battery voltage ≥ 10.8 V before power-on | 3.1 step 1 | |
| H2 | All structural plates securely fastened | 3.1 step 2 | |
| H3 | No loose cables dangling outside of robot chassis | 3.1 step 3 | |
| H4 | DYNAMIXEL motors and wheels rotate freely, no binding or resistance | 3.1 step 4 | |
| H5 | LiDAR spins freely with no jam or abnormal resistance | 3.1 step 5 | |
| H6 | Flywheel and servos launch 3 ping pong balls with no jam — `ros2 run auto_nav fat_launch` | 3.3 | |
| H7 | ArUco marker detected at 0.5 m under maze lighting — `ros2 run auto_nav fat_aruco` | 3.2 | |
| H8 | Ping pong balls slide smoothly down ramp | 3.1 step 6 | |
| H9 | Servo gate encapsulates 1 ping pong ball in idle position | 3.1 step 7 | |

### Software & Communication

| # | Check Item | Test ref. | P / F |
|---|---|---|---|
| S1 | Remote PC ↔ RPi SSH connection established | 3.4 step 1 | |
| S2 | LiDAR data received & plotted in active RViz map after launch | 3.4 step 2 | |
| S3 | No error logs or messages during testing of hardware | 3.4 step 3 | |
| S4 | Ctrl-C terminates all nodes | 3.4 step 4 | |

**FAT Sign-off — Test Conductor:** _________________ **Date:** _________________

---

## 5. Suggested Test Order

For a full bench bring-up before running the mission:

1. **Hardware inspection** (3.1) — mechanical and electrical checks, no software needed.
2. **ArUco perception** (3.2) — confirms the camera pipeline and marker detection.
3. **Launcher** (3.3) — confirms the Arduino serial bridge and flywheel + feeder hardware.
4. **Software & communication** (3.4) — confirms end-to-end connectivity and clean node lifecycle.
5. Only after all checks pass, launch the full stack via `ros2 run auto_nav mainlaunch`.

Keep terminals open during each test so ROS log output (intrinsics warnings,
decode failures, subscriber timeouts) is visible as soon as the test starts.

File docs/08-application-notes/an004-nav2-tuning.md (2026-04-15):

# Application Note — Nav2 / Exploration Tuning
AN-004 | v0.2.0 | 2026-04-15

## Purpose

This application note documents how Nav2 and frontier-based exploration
are used together in this project, which parameters were actually
tuned, and what trade-offs drove the choices. It is aimed at anyone
re-tuning exploration or navigation for a new arena.

---

## Overview

Navigation is provided by the stock **TurtleBot3 Navigation2** stack
(`turtlebot3_navigation2.launch.py`) — no custom Nav2 configuration
files are shipped with this project. SLAM is provided by
**Cartographer** (`turtlebot3_cartographer.launch.py`) and publishes
the `/map` topic that exploration consumes.

Exploration is implemented on top of Nav2 rather than as a Nav2
behaviour tree. `exploration.py` subscribes to `/map`, locates
frontiers in the occupancy grid, filters and scores them in Python,
then sends the chosen frontier as a **`NavigateToPose` action goal**.
The same node is also responsible for dispatching directed
"approach this marker" goals when the FSM publishes `EXPLORE_<id>`.

---

## Key Exploration Parameters

All frontier-search parameters are set as Python constants inside
`exploration.py` (there is currently no YAML config file for
exploration). The table below lists the values that were tuned
during integration:

| Parameter | Where | Value | Notes |
|---|---|---|---|
| Free-cell threshold | `find_frontiers` | `0 ≤ v ≤ 49` | Cells in this range count as free space candidates. |
| Unknown-cell value | `find_frontiers` | `-1` | A free cell with any `-1` neighbour is a frontier. |
| Wall threshold | `find_walls` | `50` | Occupancy ≥ 50 treated as wall. |
| `neighbor_threshold` | `choose_frontier` | 0.5 m | Radius for counting neighbouring frontier cells. |
| `min_neighbors_required` | `choose_frontier` | 5 | Frontiers with ≤ 5 neighbours are rejected (removes isolated noise). |
| `wall_distance_threshold` | `choose_frontier` | 1 cell | Minimum clearance of a candidate from the nearest wall. |
| Min robot distance | `choose_frontier` | 1.0 m | Frontiers closer than this to the robot are rejected. |
| Goal selection | `choose_frontier` | max wall distance | After filtering, the frontier with the **largest** distance to the nearest wall is chosen — biases exploration away from narrow corridors. |
| Marker approach offset | `navigate_to_marker` | 0.50 m along marker facing | Goal sits 50 cm out from the marker, robot pointing back at it. |
| Re-plan timeout | `_explore_frontiers` | 10 s | Pick a new goal if progress stalls for 10 s. |
| Close-enough distance | `navigate_to` | 0.5 m | Mark the current goal as "reached" if already within 0.5 m. |

### Marker-directed mode (`EXPLORE_<id>`)

When `EXPLORE_<id>` is received:
- If the target marker is already catalogued (its TF pose has been
  seen at least once in `map`), `navigate_to_marker` builds a pose
  facing **back at** the marker, 0.5 m out along its facing
  direction, and sends it as a `NavigateToPose` goal.
- If not catalogued yet, normal frontier search continues while the
  robot keeps listening for the marker frame on TF.

### Non-exploration states

Any state that is not `EXPLORE` / `EXPLORE_<id>` causes
`cancel_navigation()` to run, which cancels the active Nav2 goal.
This ensures exploration yields cleanly when the FSM transitions to
docking or launch.

---

## Key Nav2 Parameters

No `nav2_params.yaml` override is currently checked into the repo —
the TurtleBot3 Navigation2 default parameter set is used as-is. If
tuning becomes necessary, the conventional route is:

```bash
ros2 launch turtlebot3_navigation2 navigation2.launch.py \
    params_file:=<path to your tuned nav2_params.yaml>
```

Good starting points to tune for this robot/arena:

| Parameter | File (conventional) | Why you might touch it |
|---|---|---|
| `max_vel_x` / `max_vel_theta` | controller server | Avoid wheel slip on tight arena turns. |
| `inflation_radius` | costmap params | Keep clear of thin arena walls. |
| `robot_radius` / `footprint` | costmap params | Ensure the TurtleBot3's footprint is accurately modelled. |
| `xy_goal_tolerance` / `yaw_goal_tolerance` | goal checker | Looser tolerances make Nav2 accept frontier goals even in cluttered spots. |
| `recovery` behaviours | behaviour tree | Arena-specific stuck-recovery sequences. |

---

## SLAM / Cartographer Settings

This project uses the **default** Cartographer configuration shipped
with `turtlebot3_cartographer`. `exploration.py` makes no assumptions
about the map update rate beyond "a new `/map` arrives periodically";
the main knobs to adjust are the Lua config's resolution and
`max_range`. SLAM Toolbox is **not** used.

---

## Tuning Notes

- **Biasing exploration away from walls.** Early iterations picked
  the closest frontier to the robot, which repeatedly sent the robot
  into corners. `choose_frontier` now sorts surviving candidates by
  `wall_distance` descending and picks the frontier that is *furthest*
  from the nearest wall — this produced markedly more stable
  coverage.
- **Neighbour clustering threshold.** Setting
  `min_neighbors_required = 5` (within a 0.5 m radius) eliminated
  single-cell frontier noise caused by transient SLAM artefacts. Too
  strict a threshold starves the search at the end of a run; 5 was
  the sweet spot on the arena-sized maps tested.
- **Wall clearance in cells, not metres.** `wall_distance_threshold`
  is deliberately expressed in occupancy-grid cells rather than
  metres so it scales with the SLAM resolution without a code change.
- **Re-plan on stall.** The 10 s timeout in `_explore_frontiers`
  prevents the robot from wedging itself against a frontier Nav2
  cannot reach; exploration simply re-queries and picks the next
  best candidate.
- **Marker approach offset.** 50 cm off the marker face is the
  minimum that reliably keeps Nav2 from refusing the goal due to
  costmap inflation on the far side of the marker. If you reduce it,
  expect `NavigateToPose` goal rejections.

---

## Known Limitations

| Issue | Impact | Mitigation |
|---|---|---|
| All exploration params are hard-coded in `exploration.py`. | No runtime tuning knobs. | Convert constants to ROS 2 parameters if frequent tuning is needed. |
| Frontier scoring is O(frontiers²) due to neighbour counting. | Slow on very large maps. | Limit candidate count with a first-pass distance filter (already in place for `<1 m` from robot). |
| No dedicated `nav2_params.yaml` under version control. | Tuning changes are off-repo. | Add a checked-in params file and pass it via `params_file:=...`. |
| Exploration cancels any Nav2 goal the moment `/states` leaves `EXPLORE*`. | Can abort a goal mid-motion. | Expected behaviour — FSM is authoritative. |
| Marker directed mode assumes the marker has already been *seen once*. | If the robot hasn't spotted the marker yet, `EXPLORE_<id>` silently falls back to frontier search. | Sweep the area with normal `EXPLORE` first, or rotate in place on arrival. |

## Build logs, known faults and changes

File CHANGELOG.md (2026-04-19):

# Changelog

All notable changes to this project will be documented in this file.

The format is based on [Keep a Changelog](https://keepachangelog.com/en/1.1.0/),
and this project adheres to [Semantic Versioning](https://semver.org/spec/v2.0.0.html).

## [Unreleased]

## [2.0.0] - 2026-04-19

### Added

- FAT test procedures with detailed physical and software steps, full FAT checklist
- Docking node documented in con-ops, user manual, and key design choices
- Power budget, assembly guide, CAD model
- Launcher electronics documentation
- Application note docs (AN003 & AN004 are scaffolds to be filled)
- ICD v1.0.0
- Dynamic launching node to shoot when ArUco detected
- BOM
- Team pic

### Changed

- Arduino firmware now drives L298N instead
- Migrated ArUco detector package to remote PC
- Dynamic launch node also commands static sequence
- Updated launcher electronics controller schematic
- Increased threshold to trigger `DOCK_FAIL` from 5 (0.5s) to 20 (2s) consecutive failed TF lookups
- Camera resolution reduced to 320 x 240 and file format changed to YUYV
- Updated con-ops mission flow Phase 2 to describe three-phase docking
- Updated con-ops system architecture to include LIDAR for docking
- Docs consistency across ROS topics & nodes interactions

### Fixed

- README repo structure tree to match actual directory layout
- ArUco application note: corrected topic name, `marker_size`, `frequency`, added `benchmark` parameter
- User manual `xy_goal_tolerance` description
- Controller schematic missing resistor value & incorrect pinmap

### Removed

- remote-pc-codebase folder
- R2 auto_nav default nodes
- Rejection of TF transforms older than 0.5s for docking
- Unused r2 nodes and old aruco_detector node

## [1.0.0] - 2026-04-07

**First full major release.** The system is now capable of executing the complete mission end-to-end: autonomous exploration and mapping, docking to ArUco markers, and payload delivery. All core subsystems are operational and integrated. Known issues and edge cases remain but do not prevent mission execution.

### Added

- Full stack FSM, navigation, docking and launch ROS2 package with complete mission capability
- 40-second timeout on docking Phase 1 to prevent excessive navigation time
- Tuned docking parameters (standoff distances, tolerances, velocity limits) for improved alignment
- Tuned navigation parameters for better exploration
- Updated FSM for full ROS 2 integration with coordinated multi-stage mission control

### Removed

- `docking_test.py`, an outdated standalone docking script superseded by the current `docking.py` node

## [0.1.0] - 2026-04-06

### Added

- Initial release of the `auto_nav` ROS2 package
- Autonomous navigation with LIDAR-based obstacle avoidance
- Frontier-based exploration for unknown environment mapping
- Finite state machine (FSM) for coordinating multi-stage missions (explore, dock, launch)
- Autonomous docking using ArUco marker detection
- Live occupancy grid visualization centered on robot pose
- Keyboard teleoperation with both simple and rotation-based control
- LIDAR scanning and monitoring utilities
- RPi-based ArUco marker detection with TF transform broadcasting
- RPi-based servo and solenoid actuation triggered by LIDAR proximity

[2.0.0]: https://github.com/eggsacc/CDE2310-Docs/releases/tag/v2.0.0
[1.0.0]: https://github.com/eggsacc/CDE2310-Docs/releases/tag/v1.0.0
[0.1.0]: https://github.com/eggsacc/CDE2310-Docs/releases/tag/v0.1.0

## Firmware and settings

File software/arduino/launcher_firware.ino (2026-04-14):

// ============================================================
//  Flywheel Launcher Subsystem — simplified (no PI control)
//  Target: Arduino Uno/Nano
//  Interface: Raspberry Pi via USB Serial
//  Motor Driver: L298N (ENA=D11 PWM, IN1=D5, IN2=D6)
// ============================================================
//
//  SERIAL COMMAND PROTOCOL (from RPi)
//  -----------------------------------
//  "SPIN"    → Spin flywheel at saved PWM duty
//  "FIRE"    → Feed one ball (only acts if READY)
//  "STOP"    → Stop flywheel, return to idle
//  "PING"    → Heartbeat; Arduino replies "PONG\n"
//  "SLAUNCH" → Auto sequence: spin up, fire 3 balls with 5s gap
//  "DLAUNCH" → Reserved, not yet implemented
//
//  SERIAL RESPONSES (from Arduino)
//  -----------------------------------
//  "PONG\n"            → Response to PING
//  "READY\n"           → Flywheel running (sent immediately on SPIN)
//  "FIRED\n"           → Single ball feed cycle complete
//  "STOPPED\n"         → Flywheel stopped
//  "ERR:NOT_READY\n"   → FIRE received while not in READY state
//  "LAUNCH_COMPLETE\n" → SLAUNCH sequence finished
// ============================================================

#include <Servo.h>
#include <GyverOLED.h>

// ── Pin Definitions ──────────────────────────────────────────
#define PIN_MOTOR_PWM  11     // L298N ENA (Timer2 PWM, speed control)
#define PIN_MOTOR_INA   5     // L298N IN1 (direction)
#define PIN_MOTOR_INB   6     // L298N IN2 (direction)
#define PIN_SERVO       9     // Servo signal
#define PIN_POT         A0    // Potentiometer (config mode)
#define PIN_BUTTON      8     // Mode toggle (polled, external pull-down)

// ── Servo Config ─────────────────────────────────────────────
#define SERVO_REST_POS   10   // Degrees — ball NOT feeding
#define SERVO_FEED_POS  140   // Degrees — ball feeds into flywheel
#define SERVO_DWELL_MS  600   // Time (ms) servo holds feed position before retracting

// ── Motor Config ─────────────────────────────────────────────
#define PWM_MIN           0
#define PWM_MAX         255
#define PWM_DEFAULT     128   // Used if config mode has never been run

// ── SLAUNCH Config ───────────────────────────────────────────
#define SLAUNCH_BALLS        3     // Total balls to fire
#define SLAUNCH_SPINUP_MS  3000   // Flywheel spin-up wait before first ball (ms)
#define SLAUNCH_INTERVAL_MS 5000  // Wait between ball launches (ms), starts after servo retracts

// ── OLED / Button ────────────────────────────────────────────
#define OLED_REFRESH_MS 200   // 5 Hz
#define DEBOUNCE_MS      50

// ── Objects ──────────────────────────────────────────────────
Servo feederServo;
GyverOLED<SSH1106_128x64> oled;

// ── State ────────────────────────────────────────────────────
enum Mode     { MODE_RUN, MODE_CONFIG };
enum RunState { STATE_IDLE, STATE_READY, STATE_LAUNCHING, STATE_SLAUNCH };

Mode     currentMode = MODE_RUN;
RunState runState    = STATE_IDLE;

// ── Motor ────────────────────────────────────────────────────
int pwmDuty  = PWM_DEFAULT;
int pwmSaved = -1;            // -1 = not yet configured

// ── Servo ────────────────────────────────────────────────────
unsigned long servoFeedStart = 0;
bool          servoFeeding   = false;

// ── SLAUNCH sequence ─────────────────────────────────────────
uint8_t       slaunchBallsFired = 0;
unsigned long slaunchNextAction = 0;  // millis() timestamp for next fire

// ── OLED ─────────────────────────────────────────────────────
unsigned long lastOledUpdate = 0;

// ── Button ───────────────────────────────────────────────────
bool          lastButtonState = LOW;
unsigned long lastDebounce    = 0;
bool          buttonPressed   = false;

// ============================================================
//  Button polling
// ============================================================
void pollButton() {
  bool state = digitalRead(PIN_BUTTON);
  if (state == HIGH && lastButtonState == LOW) {
    unsigned long now = millis();
    if (now - lastDebounce > DEBOUNCE_MS) {
      buttonPressed = true;
      lastDebounce  = now;
    }
  }
  lastButtonState = state;
}

// ============================================================
//  Motor — L298N control
//  Direction is hardcoded (INA=HIGH, INB=LOW).
//  Swap motor wires physically if direction is wrong.
//  When duty=0, both direction pins driven LOW (brake).
// ============================================================
void setMotorPWM(int duty) {
  pwmDuty = constrain(duty, PWM_MIN, PWM_MAX);

  if (pwmDuty == 0) {
    digitalWrite(PIN_MOTOR_INA, LOW);
    digitalWrite(PIN_MOTOR_INB, LOW);
  } else {
    digitalWrite(PIN_MOTOR_INA, HIGH);
    digitalWrite(PIN_MOTOR_INB, LOW);
  }

  analogWrite(PIN_MOTOR_PWM, pwmDuty);
}

// ============================================================
//  Servo feed cycle (non-blocking)
//  Moves servo to feed position; updateServo() retracts it
//  after SERVO_DWELL_MS and handles post-retract logic.
// ============================================================
void startFeedCycle() {
  feederServo.write(SERVO_FEED_POS);
  servoFeedStart = millis();
  servoFeeding   = true;
}

void updateServo() {
  if (!servoFeeding) return;
  if (millis() - servoFeedStart < SERVO_DWELL_MS) return;

  // Dwell complete — retract servo immediately
  feederServo.write(SERVO_REST_POS);
  servoFeeding = false;

  if (runState == STATE_LAUNCHING) {
    // Manual FIRE — retract, return to ready
    runState = STATE_READY;
    Serial.println(F("FIRED"));

  } else if (runState == STATE_SLAUNCH) {
    // Servo fully retracted — count ball, start inter-ball wait
    // Next fire will not trigger until slaunchNextAction elapses
    // AND servoFeeding is false, guaranteeing full retract before reload
    slaunchBallsFired++;
    Serial.println(F("FIRED"));
    // If this was the LAST ball, wait only 2 seconds before stopping
    if (slaunchBallsFired >= SLAUNCH_BALLS) {
      slaunchNextAction = millis() + 2000;  // 2 seconds
    } else {
      slaunchNextAction = millis() + SLAUNCH_INTERVAL_MS;  // normal 5s
    }
  }
}

// ============================================================
//  SLAUNCH sequence state machine (non-blocking)
//  Timeline per ball:
//    [fire] → SERVO_DWELL_MS → [retract] → SLAUNCH_INTERVAL_MS → [fire next]
// ============================================================
void updateSlaunch() {
  if (runState != STATE_SLAUNCH) return;
  if (servoFeeding) return;                    // servo must be retracted first
  if (millis() < slaunchNextAction) return;    // inter-ball wait not elapsed

  if (slaunchBallsFired < SLAUNCH_BALLS) {
    startFeedCycle();                          // fire next ball
  } else {
    // All balls done
    setMotorPWM(0);
    runState = STATE_IDLE;
    Serial.println(F("LAUNCH_COMPLETE"));
  }
}

// ============================================================
//  OLED (5 Hz) — static labels drawn once in setup()
// ============================================================
const char* stateLabel() {
  if (currentMode == MODE_CONFIG) return "CONFIG  ";
  switch (runState) {
    case STATE_IDLE:      return "IDLE    ";
    case STATE_READY:     return "READY   ";
    case STATE_LAUNCHING: return "LAUNCH  ";
    case STATE_SLAUNCH:   return "SEQ     ";
    default:              return "???     ";
  }
}

void updateOLED() {
  if (millis() - lastOledUpdate < OLED_REFRESH_MS) return;
  lastOledUpdate = millis();

  oled.setCursor(40, 1);
  oled.print(F("   "));
  oled.setCursor(40, 1);
  oled.print(pwmDuty);

  oled.setCursor(40, 3);
  oled.print(F("N/A  "));   // RPM not yet implemented

  oled.setCursor(40, 5);
  oled.print(stateLabel());

  oled.update();
}

// ============================================================
//  Serial command parser
// ============================================================
void handleSerial() {
  if (!Serial.available()) return;
  String cmd = Serial.readStringUntil('\n');
  cmd.trim();

  if (cmd == F("PING")) {
    Serial.println(F("PONG"));

  } else if (cmd == F("SPIN")) {
    if (currentMode == MODE_RUN && runState == STATE_IDLE) {
      int duty = (pwmSaved >= 0) ? pwmSaved : PWM_DEFAULT;
      setMotorPWM(duty);
      runState = STATE_READY;
      Serial.println(F("READY"));
    }

  } else if (cmd == F("FIRE")) {
    if (currentMode == MODE_RUN && runState == STATE_READY) {
      runState = STATE_LAUNCHING;
      startFeedCycle();
    } else {
      Serial.println(F("ERR:NOT_READY"));
    }

  } else if (cmd == F("STOP")) {
    setMotorPWM(0);
    runState = STATE_IDLE;
    Serial.println(F("STOPPED"));

  } else if (cmd == F("SLAUNCH")) {
    // Spin up and run sequence unconditionally
    int duty = (pwmSaved >= 0) ? pwmSaved : PWM_DEFAULT;
    setMotorPWM(duty);
    slaunchBallsFired = 0;
    slaunchNextAction = millis() + SLAUNCH_SPINUP_MS;  // wait for spinup first
    runState          = STATE_SLAUNCH;

  }
}

// ============================================================
//  Mode toggle
// ============================================================
void handleModeToggle() {
  if (!buttonPressed) return;
  buttonPressed = false;

  if (currentMode == MODE_RUN) {
    currentMode = MODE_CONFIG;
    runState    = STATE_IDLE;
    int pot = map(analogRead(PIN_POT), 0, 1023, PWM_MIN, PWM_MAX);
    setMotorPWM(pot);

  } else {
    pwmSaved    = pwmDuty;
    currentMode = MODE_RUN;
    setMotorPWM(0);
  }
}

// ============================================================
//  Config mode — pot drives motor live
// ============================================================
void handleConfigMode() {
  if (currentMode != MODE_CONFIG) return;
  int pot = map(analogRead(PIN_POT), 0, 1023, PWM_MIN, PWM_MAX);
  setMotorPWM(pot);
}

// ============================================================
//  setup()
// ============================================================
void setup() {
  Serial.begin(115200);
  Serial.setTimeout(50);

  // L298N motor driver pins
  pinMode(PIN_MOTOR_PWM, OUTPUT);
  pinMode(PIN_MOTOR_INA, OUTPUT);
  pinMode(PIN_MOTOR_INB, OUTPUT);
  digitalWrite(PIN_MOTOR_INA, LOW);
  digitalWrite(PIN_MOTOR_INB, LOW);
  analogWrite(PIN_MOTOR_PWM, 0);

  feederServo.attach(PIN_SERVO);
  feederServo.write(SERVO_REST_POS);

  pinMode(PIN_BUTTON, INPUT);   // external pull-down

  // OLED — draw static labels once
  oled.init();
  oled.clear();
  oled.update();
  oled.setScale(1);
  oled.setCursor(5, 1);
  oled.print(F("PWM: "));
  oled.setCursor(5, 3);
  oled.print(F("RPM: "));
  oled.setCursor(5, 5);
  oled.print(F("Mode: "));
  oled.update();

  Serial.println(F("LAUNCHER_READY"));
}

// ============================================================
//  loop()
// ============================================================
void loop() {
  pollButton();
  handleModeToggle();
  handleSerial();
  handleConfigMode();
  updateServo();
  updateSlaunch();
  updateOLED();
}

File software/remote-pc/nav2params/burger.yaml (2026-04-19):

amcl:
  ros__parameters:
    use_sim_time: False
    alpha1: 0.1
    alpha2: 0.1
    alpha3: 0.05
    alpha4: 0.05
    alpha5: 0.05
    base_frame_id: "base_footprint"
    beam_skip_distance: 0.5
    beam_skip_error_threshold: 0.9
    beam_skip_threshold: 0.3
    do_beamskip: false
    global_frame_id: "map"
    lambda_short: 0.1
    laser_likelihood_max_dist: 2.0
    laser_max_range: 100.0
    laser_min_range: -1.0
    laser_model_type: "likelihood_field"
    max_beams: 60
    max_particles: 1000
    min_particles: 500
    odom_frame_id: "odom"
    pf_err: 0.05
    pf_z: 0.99
    recovery_alpha_fast: 0.0
    recovery_alpha_slow: 0.0
    resample_interval: 1
    robot_model_type: "nav2_amcl::DifferentialMotionModel"
    save_pose_rate: 0.5
    sigma_hit: 0.2
    tf_broadcast: true
    transform_tolerance: 0.5
    update_min_a: 0.2
    update_min_d: 0.1
    z_hit: 0.5
    z_max: 0.05
    z_rand: 0.5
    z_short: 0.05
    scan_topic: scan

amcl_map_client:
  ros__parameters:
    use_sim_time: False

amcl_rclcpp_node:
  ros__parameters:
    use_sim_time: False

bt_navigator:
  ros__parameters:
    use_sim_time: False
    global_frame: map
    robot_base_frame: base_link
    odom_topic: /odom
    default_bt_xml_filename: "navigate_w_replanning_and_recovery.xml"
    bt_loop_duration: 10
    default_server_timeout: 20
    enable_groot_monitoring: True
    groot_zmq_publisher_port: 1666
    groot_zmq_server_port: 1667
    plugin_lib_names:
    - nav2_compute_path_to_pose_action_bt_node
    - nav2_compute_path_through_poses_action_bt_node
    - nav2_follow_path_action_bt_node
    - nav2_back_up_action_bt_node
    - nav2_spin_action_bt_node
    - nav2_wait_action_bt_node
    - nav2_clear_costmap_service_bt_node
    - nav2_is_stuck_condition_bt_node
    - nav2_goal_reached_condition_bt_node
    - nav2_goal_updated_condition_bt_node
    - nav2_initial_pose_received_condition_bt_node
    - nav2_reinitialize_global_localization_service_bt_node
    - nav2_rate_controller_bt_node
    - nav2_distance_controller_bt_node
    - nav2_speed_controller_bt_node
    - nav2_truncate_path_action_bt_node
    - nav2_goal_updater_node_bt_node
    - nav2_recovery_node_bt_node
    - nav2_pipeline_sequence_bt_node
    - nav2_round_robin_node_bt_node
    - nav2_transform_available_condition_bt_node
    - nav2_time_expired_condition_bt_node
    - nav2_distance_traveled_condition_bt_node
    - nav2_single_trigger_bt_node
    - nav2_is_battery_low_condition_bt_node
    - nav2_navigate_through_poses_action_bt_node
    - nav2_navigate_to_pose_action_bt_node
    - nav2_remove_passed_goals_action_bt_node
    - nav2_planner_selector_bt_node
    - nav2_controller_selector_bt_node
    - nav2_goal_checker_selector_bt_node

bt_navigator_rclcpp_node:
  ros__parameters:
    use_sim_time: False

controller_server:
  ros__parameters:
    use_sim_time: False
    controller_frequency: 10.0
    min_x_velocity_threshold: 0.001
    min_y_velocity_threshold: 0.5
    min_theta_velocity_threshold: 0.001
    failure_tolerance: 0.3
    progress_checker_plugin: "progress_checker"
    goal_checker_plugins: ["general_goal_checker"]
    controller_plugins: ["FollowPath"]

    # Progress checker parameters
    progress_checker:
      plugin: "nav2_controller::SimpleProgressChecker"
      required_movement_radius: 0.5
      movement_time_allowance: 10.0

    general_goal_checker:
      stateful: True
      plugin: "nav2_controller::SimpleGoalChecker"
      xy_goal_tolerance: 0.25
      yaw_goal_tolerance: 0.25

    # DWB parameters
    FollowPath:
      plugin: "dwb_core::DWBLocalPlanner"
      debug_trajectory_details: True
      min_vel_x: 0.0
      min_vel_y: 0.0
      max_vel_x: 0.22
      max_vel_y: 0.0
      max_vel_theta: 1.0
      min_speed_xy: 0.0
      max_speed_xy: 0.22
      min_speed_theta: 0.0
      # Add high threshold velocity for turtlebot 3 issue.
      # https://github.com/ROBOTIS-GIT/turtlebot3_simulations/issues/75
      acc_lim_x: 2.5
      acc_lim_y: 0.0
      acc_lim_theta: 3.2
      decel_lim_x: -2.5
      decel_lim_y: 0.0
      decel_lim_theta: -3.2
      vx_samples: 20
      vy_samples: 0   
      vtheta_samples: 40
      sim_time: 1.5
      linear_granularity: 0.05
      angular_granularity: 0.025
      transform_tolerance: 0.2
      xy_goal_tolerance: 0.05
      trans_stopped_velocity: 0.25
      short_circuit_trajectory_evaluation: True
      stateful: True
      critics: ["RotateToGoal", "Oscillation", "BaseObstacle", "GoalAlign", "PathAlign", "PathDist", "GoalDist"]
      BaseObstacle.scale: 0.05
      PathAlign.scale: 32.0
      PathAlign.forward_point_distance: 0.1
      GoalAlign.scale: 24.0
      GoalAlign.forward_point_distance: 0.1
      PathDist.scale: 32.0
      GoalDist.scale: 24.0
      RotateToGoal.scale: 32.0
      RotateToGoal.slowing_factor: 5.0
      RotateToGoal.lookahead_time: -1.0

controller_server_rclcpp_node:
  ros__parameters:
    use_sim_time: False
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

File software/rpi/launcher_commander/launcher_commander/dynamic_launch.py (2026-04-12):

"""
dynamic_launcher.py — ROS2 node for launching ping pong balls at a moving ArUco target.

Overview
--------
This node listens for a "DYNAMIC_LAUNCH" command on /states, then monitors
the TF tree for a specific ArUco marker. When the target marker is detected,
it sends serial commands to an Arduino-driven launcher (flywheel + servo feeder)
to fire ping pong balls. Designed for scenarios where the target moves past a
narrow window of visibility (e.g. a hole in a wall).

Subscribed Topics
-----------------
/states : std_msgs/String
    Main FSM command topic. This node activates when it receives "DYNAMIC_LAUNCH".
/current_marker : std_msgs/Int32
    ID of the currently detected ArUco marker (published by the detection node).

Published Topics
----------------
/operation_status : std_msgs/String
    Feedback to the main FSM. Possible values:
    - "LAUNCH_DONE"    : All shots fired successfully.
    - "LAUNCH_TIMEOUT" : Timed out, whether zero or some shots were fired.

TF Dependencies
---------------
Expects ArUco marker frames named "aruco_marker_{id}" in the TF tree,
resolved relative to "base_link".

Parameters
----------
target_marker_id : int (default: 5)
    The ArUco marker ID to look for in the TF tree.
serial_port : str (default: '/dev/arduino_launcher')
    Serial port for the Arduino launcher. Use a udev symlink for stability.
baud_rate : int (default: 115200)
    Baud rate for serial communication.
launch_delay : float (default: 1.0)
    Seconds to wait after detecting the marker before firing. Acts as lead
    time compensation for a moving target.
node_timeout : float (default: 30.0)
    Seconds before the node gives up if no marker is detected (or if not
    all shots have been fired).
max_shots : int (default: 3)
    Total number of balls to fire before completing.
shot_cooldown : float (default: 2.0)
    Minimum seconds between consecutive shots. Allows the servo feeder
    to reset between fires.

Serial Protocol (to Arduino)
-----------------------------
"SPIN"  — Spin up the flywheel. Must be sent before any FIRE commands.
"FIRE"  — Fire a single ping pong ball.
"STOP"  — Cease all launcher operations.

Node Lifecycle
--------------
1. Idle until "DYNAMIC_LAUNCH" is received on /states.
2. Sends "SPIN" to Arduino.
3. Polls TF tree at 10 Hz for aruco_marker_{target_marker_id}.
4. On detection, waits launch_delay seconds, then sends "FIRE".
5. Respects shot_cooldown between consecutive shots.
6. After max_shots fired → sends "STOP", publishes "LAUNCH_COMPLETE".
7. On timeout → sends "STOP", publishes "LAUNCH_TIMEOUT" or "LAUNCH_INCOMPLETE".

Example Launch
--------------
    ros2 run your_package dynamic_launcher --ros-args \\
        -p target_marker_id:=5 \\
        -p launch_delay:=1.0 \\
        -p shot_cooldown:=2.0 \\
        -p node_timeout:=30.0 \\
        -p serial_port:=/dev/arduino_launcher \\
        -p max_shots:=3
"""

import rclpy
from rclpy.node import Node
from std_msgs.msg import String, Int32
from tf2_ros import Buffer, TransformListener
import serial
import re


class DynamicLauncherNode(Node):
    """ROS2 node that fires ping pong balls at a target ArUco marker via an Arduino launcher."""

    def __init__(self):
        super().__init__('dynamic_launcher_node')

        # Parameters
        self.declare_parameter('target_marker_id', 5)
        self.declare_parameter('serial_port', '/dev/arduino_launcher')
        self.declare_parameter('baud_rate', 115200)
        self.declare_parameter('launch_delay', 1.0)       # seconds to wait before firing (moving target lead time)
        self.declare_parameter('node_timeout', 30.0)       # seconds before giving up if no marker detected
        self.declare_parameter('max_shots', 3)
        self.declare_parameter('shot_cooldown', 2.0)      # minimum seconds between consecutive shots

        self.target_id = self.get_parameter('target_marker_id').value
        port = self.get_parameter('serial_port').value
        baud = self.get_parameter('baud_rate').value
        self.launch_delay = self.get_parameter('launch_delay').value
        self.node_timeout = self.get_parameter('node_timeout').value
        self.max_shots = self.get_parameter('max_shots').value
        self.shot_cooldown = self.get_parameter('shot_cooldown').value

        # Serial connection to Arduino
        try:
            self.ser = serial.Serial(port, baud, timeout=1)
            self.get_logger().info(f'Serial connected on {port} @ {baud}')
        except serial.SerialException as e:
            self.get_logger().fatal(f'Failed to open serial port: {e}')
            raise SystemExit(1)

        # TF2 for marker detection
        self.tf_buffer = Buffer()
        self.tf_listener = TransformListener(self.tf_buffer, self)

        # Publishers and subscribers
        self.status_pub = self.create_publisher(String, '/operation_status', 10)
        self.state_sub = self.create_subscription(String, '/states', self.state_callback, 10)
        self.marker_sub = self.create_subscription(Int32, '/current_marker', self.marker_callback, 10)

        # State tracking for dynamic
        self.active = False
        self.flywheel_spinning = False
        self.shots_fired = 0
        self.current_marker_id = None
        self.waiting_to_fire = False
        self.last_fire_time = None  # tracks when the last shot was fired

        # State tracking for static
        self.static = False
        self.static_shots_fired = 0


        # Timers (created on activation)
        self.timeout_timer = None
        self.delay_timer = None
        self.poll_timer = self.create_timer(0.05, self.poll_serial)
        self.marker_check_timer = None

        self.get_logger().info(
            f'Dynamic launcher ready. Target marker: {self.target_id}, '
            f'Max shots: {self.max_shots}, Delay: {self.launch_delay}s, '
            f'Cooldown: {self.shot_cooldown}s, Timeout: {self.node_timeout}s'
        )

    # ── State machine activation ──────────────────────────────────────

    def state_callback(self, msg: String):
        command = msg.data.strip()
        if command == 'DYNAMIC_LAUNCH' and not self.active:
            self.get_logger().info('DYNAMIC_LAUNCH received. Activating.')
            self.activate()
        elif command == 'STATIC_LAUNCH' and not self.static:
            self.get_logger().info('STATIC_LAUNCH received. Activating static mode.')
            self.activate_static()

    # ── Static activation ──────────────────────────────────────

    def activate_static(self):
        self.static = True
        self.static_shots_fired = 0

        self.send_serial_command('SPIN')
        self.get_logger().info('Static mode: spinning up, firing 3 balls with 5.5s delay.')

        # Fire first ball immediately (after a brief spin-up moment)
        self.static_fire_timer = self.create_timer(0.5, self.static_fire_once)
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

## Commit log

2026-04-04 docs(subsystem-design): added in description of docking node and flowchart (#10)
2026-04-07 docs(ros2-package): fixed missing symlink files. removed lidar-servo package under rpi. (#22)
2026-04-07 Sw/arduino firmware (#28)
    * docs(software): moved all packages and firmware code under software.
    * feat(software): added arduino launcher control firmware.
    * docs(changelog): update changelog
2026-04-10 feat(launcher): added dynamic launch node. docs(electronics): updated elec subsystems docs. docs(hardware): updated cad renders in hw subsystem. (#43)
2026-04-11 docs(hw/elec): updated CAD render & animations. updated launcher controller schematic. (#44)
2026-04-12 sw(launcher): fixed launcher node messages type mismatch. removed dynamic_launch command from arduino firmware & launcher commander. docs(software): added detailed software overview. added node docum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
    [dynamic_launch.py, launcher_cmd.py, launcher_firware.ino]
2026-04-12 Sw/docking fix (#50)
    * fix(docking): removed rejection of stale tf transforms and increased threshold to trigger DOCK_FAIL to 20 consecutive missed TF transforms
    * fix(docking): increased standoff distances and docking tolerances
    * fix(docking): updated new tolerances and no. of iterations for consecutive tf lookup failures before timeout
2026-04-12 Sw/launcher dynamic (#51)
    * feat(launcher): added static laucnhing into dynamic launch file, changed aruco marker 5 detection to make sure its only if the aruco marker is actually present, and not using old tf transforms
    * fix(fsm): changed transition state to not publish mesages, chenged dock success code so self.state does not have to be dock, since we are using DOCK_1/DOCK_2 now.
    [dynamic_launch.py]
2026-04-13 docs(icd,software): removed unused /current_marker topic documentation from icd and software documents (#55)
2026-04-13 Sw/dockstatus (#59)
    * feat(exploration): added function to store aruco marker location
    * feat(fsm): added fsm explore status
    * feat(fsm/docking): added docking states to fsm, added working nav2 docking towards aruco marker
    * fix(fsm): changed nav2 docking distance to 0.2 -> 0.5
    * fix(mainalunch): added aruco_detector to startup
    * feat(aruco_detector): added aruco detection into remote pc instead of rpi using compressed image
    * fix(fsm.setup,mainlaunch,aurco_detector): fixed everything to better calibrate
    [dynamic_launch.py]
2026-04-14 feat(arduino-firmware): updated arduino firmware to drive L298N driver instead (#60)
2026-04-15 Docs/update description (#65)
    * docs(icd, changelog): initial updating of icd to for 130DC motor to use isolated 9v battery power and updated format of changelog to keep a changelog format
    * docs(node-docs): rewrite fsm/docking/exploration and add aruco_detector2, dynamic_launch, mainlaunch summaries
    * docs(software): update subsystem-design for current deployment and topic set
    * docs(icd): update /states, /operation_status, and add /arduino_cmd interface
    * docs(an003): rewrite docking AN against docking.py and aruco_de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
2026-04-15 Feat/arduino bridge (#67)
    * feat(arduino-firmware): updated arduino firmware to drive L298N driver instead
    * feat(arduino-bridge): added arduino bridge node under rpi package
2026-04-19 docs(bom): modified bom folder
2026-04-19 Docs/elec (#70)
    * docs(hardware): added assembly guide. added CAD model
    * docs(elec): added power budgeting and launcher controller electronics.
    - good job eggsacc
2026-04-19 docs(hardware): added assembly guide. added CAD model (#71)
    good job eggsacc!
2026-04-19 Docs/hw (#73)
    * docs(hw): added manufacturing guide and 3D printed components STL
    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
    [90 angled ramp (1) x2.stl, 90 angled ramp (2) x2.stl, 90 angled ramp (3) x2.stl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]
2026-04-19 docs(hw): renamed STLs folder, updates README directory tree (#83)
    [90 angled ramp (1) x2.stl, 90 angled ramp (2) x2.stl, 90 angled ramp (3) x2.stl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]
2026-04-19 docs(bom): moved bom folder

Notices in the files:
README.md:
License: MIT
